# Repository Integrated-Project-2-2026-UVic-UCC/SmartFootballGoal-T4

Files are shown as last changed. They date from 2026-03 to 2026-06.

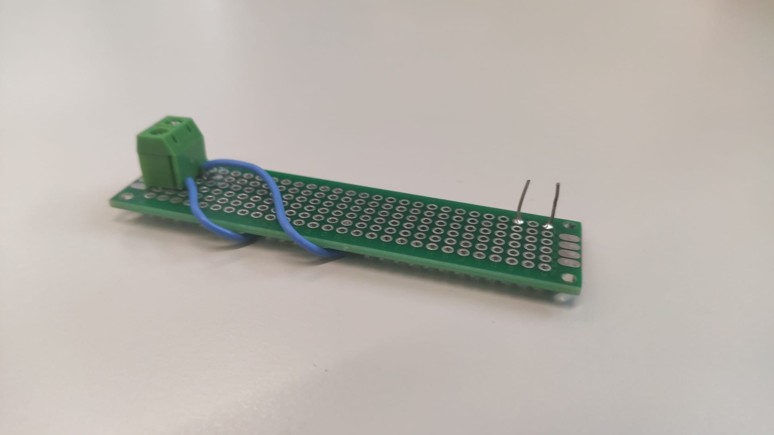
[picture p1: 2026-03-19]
Electronics/PCB 1.jpeg

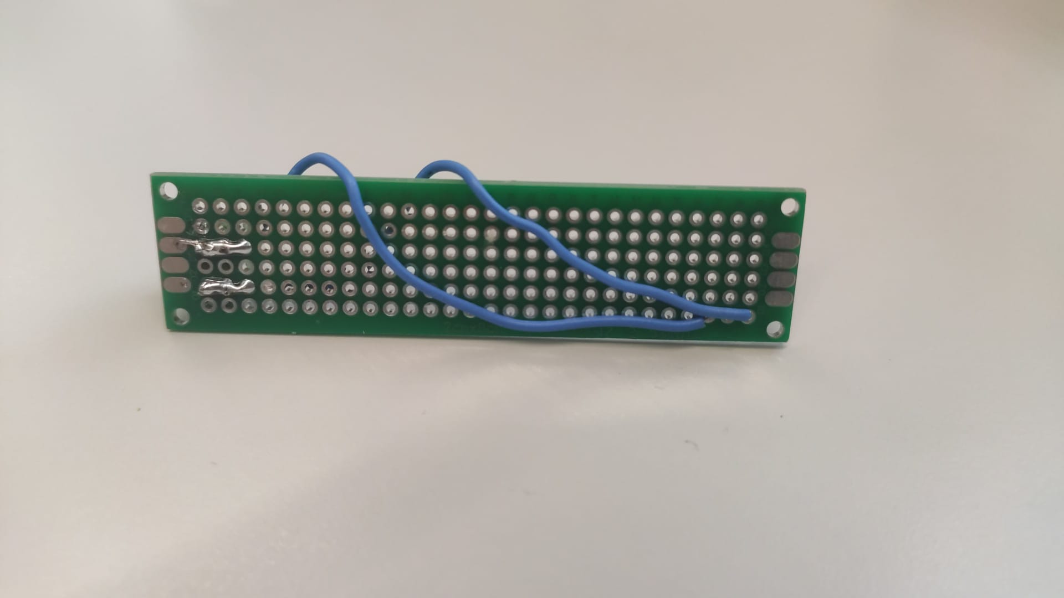
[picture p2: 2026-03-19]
Electronics/PCB 2.jpeg

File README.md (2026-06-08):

<div align="center">
  <h1>⚽ SmartGoal</h1>

  SmartGoal Demo (https://www.youtube.com/watch?v=oHqELqLCC2w)

</div>

### Computer-vision football goal with real-time ball tracking, speed measurement, and automatic slow-motion recording.

We are four Mechatronics Engineering students at UVIC and we built SmartGoal as our Integrated Projects II final prototype. The goal detects shots, measures ball speed in real time, records a slow-motion clip of every goal, and serves everything through a web dashboard hosted on the Raspberry Pi itself — no internet connection, no external infrastructure.

- Fully open-source — **hardware**, **software**, **firmware**.
- Runs on a **Raspberry Pi 4b** with a standard **Camera Module V2**.
- Ball tracking at up to **90 FPS** using OpenCV colour segmentation.
- **3D position and velocity** calculated from a single camera using the pinhole camera model.
- **4× slow-motion** goal clips saved automatically and accessible from any device on the local network.
- **Headless operation** — no monitor required after first setup.

---

## Built for tinkerers

SmartGoal is **not a finished product**. We built it in a university workshop with aluminium profiles, a drill press, and a 3D printer, and we expect you to do the same.

The aluminium goal frame is 100 cm wide, 65 cm tall, and 30 cm deep. The camera mounts on a custom support arm 60 cm behind and 35 cm above the crossbar. All structural parts are bolted together with M10 hardware — no welding required.

If you want a simpler build, you can mount the camera system on any existing goal of similar dimensions without building the frame from scratch.

---

## How it works

The camera captures frames at up to 90 FPS with a fixed 2000 µs exposure to keep the ball sharp at high speeds. Each frame is converted to HSV colour space and thresholded to isolate the ball. The largest matching contour is fitted with a minimum enclosing circle. If the circle radius exceeds the minimum threshold, the detection is accepted.

The detected radius in pixels is used to compute depth (Z axis) through the pinhole camera model: knowing the real ball diameter (20.4 cm) and the apparent pixel diameter, the system back-calculates the distance to the camera. Lateral position (X, Y) is derived from the pixel offset from the image centre scaled by the depth.

Velocity is the 3D Euclidean distance between consecutive positions divided by the elapsed time between frames, smoothed with an exponential moving average (α = 0.7).

A goal is registered when three conditions are met simultaneously: the ball is inside the configured depth window, speed exceeds the minimum threshold, and the cooldown period since the last trigger has elapsed.

When a goal is triggered, the system slices a 2-second window from the rolling frame buffer (1 s before and 1 s after the event), writes it at 1/4 of the real frame rate to produce 4× slow motion, re-encodes it to H.264 with ffmpeg for browser compatibility, and registers it with the web server.

---

# Getting started

## 1. Hardware

### 1.1 Electronics

| Component | Notes |
|---|---|
| Raspberry Pi 4b (4 GB or 8 GB) | Main processing unit |
| Raspberry Pi Camera Module V2 | Connected via CSI ribbon cable |
| USB-C power adapter (5 V / 3 A minimum) | Official Raspberry Pi adapter recommended |

Power the Raspberry Pi through the USB-C port. The camera draws power directly from the CSI connector — no additional wiring is needed.

### 1.2 Mechanical build

The goal frame uses 50 × 50 × 2 mm hollow square aluminium profiles bolted together with metallic angle brackets and M10 hardware.

**Dimensions:**
- Width: 1000 mm
- Height: 650 mm  
- Depth: 300 mm
- Rear support angle: 65.2° (calculated from the 650/300 geometry)
- Camera support arm: 600 mm horizontal + 350 mm vertical extension

**3D-printed parts** (PLA, designed in PTC Creo):
- End caps for open profile ends (45.90 × 43.40 mm, 2.50 mm height)
- Camera and Raspberry Pi enclosure support base (110 × 110 mm)
- Auxiliary fixation bracket (35 × 25 mm)

All STL files are in the `mechanical/` folder.

---

## 2. Software setup

### 2.1 Install dependencies

```bash
sudo apt update
sudo apt install -y python3-pip ffmpeg network-manager
pip3 install opencv-python picamera2 flask numpy
```

### 2.2 Clone the repository

```bash
git clone https://github.com/your-username/SmartGoal.git
cd SmartGoal
```

### 2.3 Configure the system

All parameters are in `config.py`:

```python
BALL_DIAMETER_M    = 0.204       # real ball diameter in metres
H_FOV              = 62.2        # horizontal field of view of your camera
IMG_W, IMG_H       = 640, 480    # capture resolution
CALIBRATION_FACTOR = 2.14        # lens distortion correction — recalibrate for your setup
HSV_LOWER          = (108, 134, 121)   # lower HSV bound for ball colour
HSV_UPPER          = (121, 255, 255)   # upper HSV bound for ball colour
GOAL_ZONE_NEAR     = 0.895       # near edge of goal plane in metres
GOAL_ZONE_FAR      = 0.905       # far edge of goal plane in metres
GOAL_MIN_VELOCITY  = 1.0         # minimum speed to register a goal (m/s)
SLOWMO_FACTOR      = 4           # slow-motion multiplier for saved clips
```

The HSV bounds and calibration factor depend on your ball colour and lens. See the calibration section below.

### 2.4 Run

```bash
python3 main.py
```

On startup the system creates a Wi-Fi hotspot named **SFGoal** (password: **football1**). Connect any device to that network and open `http://192.168.4.1:5000` in a browser to access the dashboard.

If an HDMI display is connected, a live preview window opens automatically. Without a display the system runs in headless mode — tracking, recording, and the web server all continue to work.

Press **Q** in the preview window or `Ctrl+C` in the terminal to stop.

---

## 3. Calibration

### 3.1 Ball colour (HSV thresholds)

Run the calibration tool with the system live:

```bash
python3 calibrate_hsv.py
```

Adjust the sliders until only the ball is visible in the mask preview. Copy the resulting `HSV_LOWER` and `HSV_UPPER` values into `config.py`.

### 3.2 Camera field of view

```bash
python3 calibrate_fov.py
```

Press `+` / `-` to adjust the crop factor until the goal opening fills the frame comfortably. Press `S` to save the resulting `H_FOV` value to `config.py`.

### 3.3 Depth calibration

Place the ball at a known distance from the camera (e.g. 1.00 m) and run the system. Read the reported Z value from the terminal or dashboard. Adjust `CALIBRATION_FACTOR` in `config.py` using:

```
CALIBRATION_FACTOR = CALIBRATION_FACTOR × (real_distance / reported_Z)
```

Repeat until the reported distance matches the real distance within acceptable error.

---

## 4. File structure

```
SmartGoal/
├── main.py          # entry point — initialises all components and runs the capture loop
├── config.py        # all tunable constants
├── detection.py     # detect_ball() — HSV segmentation and circle fitting
├── tracker.py       # BallTracker — 3D position and velocity from pixel detections
├── recording.py     # GoalRecorder — rolling buffer and background video writer
├── server.py        # Flask web dashboard
├── hotspot.py       # Wi-Fi hotspot management
├── sources.py       # CameraSource — PiCamera2 wrapper
├── drawing.py       # draw_ball() — live preview annotation
├── calibrate_fov.py # interactive FOV calibration tool
└── mechanical/      # STL files and CAD drawings
```

---

## 5. Troubleshooting

**Camera not found / PiCamera2 error**

Make sure no other process is using the camera:

```bash
sudo pkill -f python3
sudo fuser -k /dev/video0 2>/dev/null
sleep 2
python3 main.py
```

**Hotspot not starting**

```bash
sudo apt install -y network-manager
sudo systemctl enable NetworkManager
sudo systemctl start NetworkManager
```

**Videos not playing in the browser**

ffmpeg must be installed for H.264 re-encoding:

```bash
sudo apt install -y ffmpeg
```

**Ball not detected**

Recalibrate the HSV thresholds under your current lighting conditions. Detection is sensitive to ambient light changes — the system works best under consistent indoor lighting.

---

## Built by

Sergi Ocaña, Mireia Sabaté, Martí Sayago, Oleguer Treserra  
Degree in Mechatronics Engineering — UVIC, 2026

Tutor: Clara I. Sandino, Moises Garin Escriva
```

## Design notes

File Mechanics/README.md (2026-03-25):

## 🏗️ Mechanical Design: Field Deployment

The mechanical structure ensures the electronics survive the impact and environmental conditions of a football pitch.

### 📐 Optimal Geometry
- **FOV Coverage:** Based on the lens's **62.2° HFOV**, the camera is mounted exactly **75 cm** from the goal line. This allows the system to monitor the entire **90 cm x 60 cm** goal aperture in a single frame.
- **Angle of Attack:** The camera is positioned at a slight incline to maximize the visible "Z-depth" as the ball approaches the net.

### 🛡️ Impact & Protection
- **Vibration Isolation:** The Raspberry Pi is mounted on rubber standoffs inside the case to protect the CPU and SD card from the shock of the ball hitting the frame.
- **Lens Shield:** A high-transparency polycarbonate plate protects the camera lens from high-velocity direct impacts without distorting the optical path.

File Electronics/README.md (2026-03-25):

## ⚡ Electronics: High-Performance Edge Computing

The electronic heart of SmartGoal is designed for low-latency image processing and stable high-speed data acquisition.

### 🧠 Core Components
- **Raspberry Pi 4 (8GB RAM):** Handles the parallel execution of the OS, camera stream, and OpenCV mathematical calculations.
- **Sony IMX219 Camera Module:** An 8MP sensor capable of high-speed video modes (90-120 FPS), connected via a dedicated 15-pin **CSI (Camera Serial Interface)**.
- **Power Management:** 5V/3A USB-C power delivery with an integrated 10,000mAh battery for 4+ hours of pitch-side operation.
- **Thermal Solution:** Active cooling (PWM Fan) and aluminum heatsinks to prevent CPU throttling during intensive 3D math processing.

### 🔌 Connectivity & Signal Flow
1. **Raw Input:** The IMX219 sensor sends raw Bayer data through the CSI bus to the Pi's GPU.
2. **Hardware Decoding:** The ISP (Image Signal Processor) converts data to a BGR888 array.
3. **Feedback Output:** Real-time data is displayed via Micro-HDMI or transmitted over 5GHz Wi-Fi for remote monitoring.

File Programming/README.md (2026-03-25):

## 💻 Programming: The Vision Pipeline

The software architecture is a custom-built **Object Tracking & Physics Engine** written in Python 3.

### 👁️ Computer Vision Pipeline
- **HSV Space Isolation:** To handle changing outdoor light, the code converts frames to **HSV (Hue, Saturation, Value)**. This allows for stable color tracking even under heavy shadows or bright sunlight.
- **Morphological Filtering:** Uses **Gaussian Blurring**, **Erosion**, and **Dilation** to eliminate "salt and pepper" noise from the grass and player movement.
- **Circularity Algorithm:** To prevent tracking non-ball objects, every detected shape is put through a circularity test:
  $$Circularity = 4\pi \times \frac{Area}{Perimeter^2}$$
  *Only objects with a ratio $> 0.6$ (indicating a spherical shape) are accepted.*

### 📐 3D Physics Engine
- **Depth Estimation (Z-axis):** Based on the **Pinhole Camera Model**, the code calculates ball distance by comparing its pixel diameter to its real-world size (22.5cm):
  $$Z = \frac{BallDiameter \times FocalLength}{PixelDiameter}$$
- **3D Velocity Vector:** The system tracks the Euclidean distance between frames in a 3D coordinate system $(X, Y, Z)$:
  $$\text{Speed} = \frac{\sqrt{\Delta X^2 + \Delta Y^2 + \Delta Z^2}}{\Delta Time}$$
- **Smoothing:** A weighted **Exponential Moving Average (EMA)** filter stabilizes the speed output, removing jitter from pixel noise.

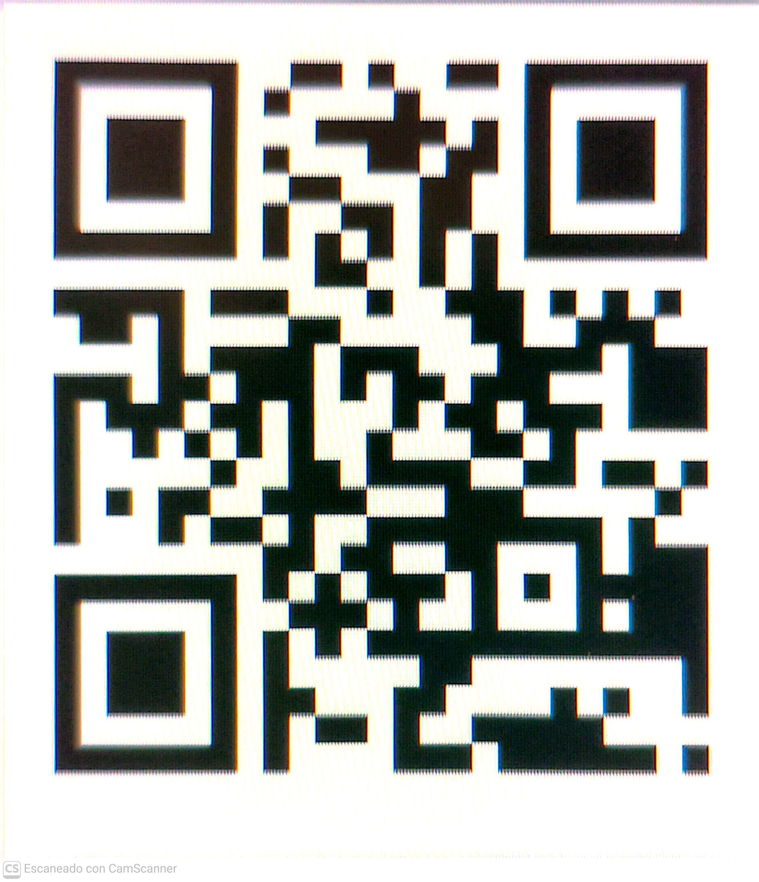
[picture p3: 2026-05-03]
Programming/football_goal/Final_version/QR_wifi.jpg

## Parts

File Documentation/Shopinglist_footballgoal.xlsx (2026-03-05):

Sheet: Project Specifications
TECHNICAL SPECIFICATIONS
Customer Company | Universitat de Vic - Universitat Central de Catalunya
Engineering Company | Smart Football Goal
Revision 1 | Date: 5/03/2026
List the main characteristics of the desired device
Item number | Description
1 | Capable of registering the velocity and position of the ball
2 | Dureble enought to handle shoots in any direction
3 | Collects the information and sends it to a webpage
Mechanical part
Dimensions (volume) | 600 mm x 300 mm x 900 mm (height)
Weight | 5,8 kg (aprox)
Wheels | no weels
Materials for the mechanical part / structure | 3D printed parts and aluminium tube
Motors | no motor
Degrees of freedom | 0
Manufacturing equipment | 3D Printer, industrial drills, cutting machines
Assembly between parts | Bolts and nuts, welding for electrical and electronics parts
Electronic & programming part
Microcontroller | Raspberry Pi 5 4GB
Drivers | Native driver (so no needed)
Sensors | Arducam IMX296 Global Shutter Camera
Communication | Via Wifi
Programming | Phython and OpenCv
Power | Connected to the socket
Autonomy | Indef
Protoboard | No

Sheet: Conceptual_Design
CONCEPTUAL DESIGN
Include an image (or more than one) with the current status of the conceptual design. Can be a sketches done with pencil

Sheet: Shopping list
PRELIMINAR ORDER LIST
Team: | smart football goal(team 4) |  |  | Total cost [€] | 271.17 |  | 28.83
 |  |  |  | Budget limit [€] | 300
Item number | Description of the material | Quantity |  | Price [€] | Cost [€] | Provider | Link / website
1 | goalpost tubes | 6 | m | 6.56 | 39.36 |  | https://www.alacermas.com/es/producto/tubos-cuadrados-extruidos-de-aluminio | .
2 | ESP 32 | 1 |  | 8.90 | 8.90 |  | https://www.amazon.es/desarrollo-AYWHP-ESP-WROOM-32-Bluetooth-Compatible/dp/B0DG8JFY3C | .
3 | regulator (5 a 3,3v) | 1 |  | 11.99 | 11.99 |  | https://www.amazon.es/Convertidor-ajustable-reductor-regulador-voltaje/dp/B0D9HSRQSB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
4 | Cargols M8 85mm | 20 | en el paquet hi ha 30, pero nomes necessitarem aprox 20 | 15.87 | 15.87 |  | https://www.tornillos-express.es/carrito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 | ,
6 | femella M8 85mm | 20 | en el paquet hi ha 100, pero nomes necessitarem aprox 20 | 1.33 | 1.33 |  | https://www.tornillos-express.es/tornillo-metales-cabeza-hexagonal-th-109-iso-4017/43047-632626-tornillo-metales-cabeza-hexagonal-m8x80-clase-109-acero-cincad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
7 | Goal net | 1 |  | 25.66 | 25.66 |  | https://www.amazon.es/dp/B0CJJCG4B2?aref=WCCGjsiMEK&sp_csd=d2lkZ2V0TmFtZT1zcF9kZXRhaWw | ,
8 | Arducam IMX296 Global Shutter Camera | 1 |  | 70.99 | 70.99 |  | https://www.arducam.com/1-58mp-imx296-color-global-shutter-camera-module-with-m12-lens-for-raspberry-pi.html | . | price arducam
9 | Raspberry Pi 5 4GB | 1 |  | 97.07 | 97.07 |  | https://www.amazon.es/Raspberry-Pi-SC1111-5-4Gb/dp/B0CK3L9WD3?__mk_es_ES=ÅMÅŽÕÑ | .
10 |  |  |  |  | 0
11 |  |  |  |  | 0
12 |  |  |  |  | 0
13 |  |  |  |  | 0
14 |  |  |  |  | 0
15 |  |  |  |  | 0
16 |  |  |  |  | 0
17 |  |  |  |  | 0
18 |  |  |  |  | 0
19 |  |  |  |  | 0
20 |  |  |  |  | 0

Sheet: Recommended suppliers
Provider | Description | link
RS Online | distributor of electronics, electricity and industrial maintenance products | https://es.rs-online.com/
BCN 3D Technologies | 3D Printing Filament distributor for our 3D printer BCN 3D Sigma | https://www.bcn3dtechnologies.com/ca/
Robotshop | Stepper motor, grippers, servo motors, arduinos, raspberry Pi, drivers for motors | https://www.robotshop.com/
Motedis | Mechanical components, aluminium profiles | https://www.motedis.es/shop/index.php
Amazon | Electronics and more | https://www.amazon.es/
ALACER MAS | Mechanical components, aluminium profiles | http://www.alacermas.com/index.php
Please check also the list of recommended providers in the virtual campus.
https://campus.uvic.cat/aules/pluginfile.php/830007/mod_resource/content/2/IP2_List_of_possible_providers.pdf

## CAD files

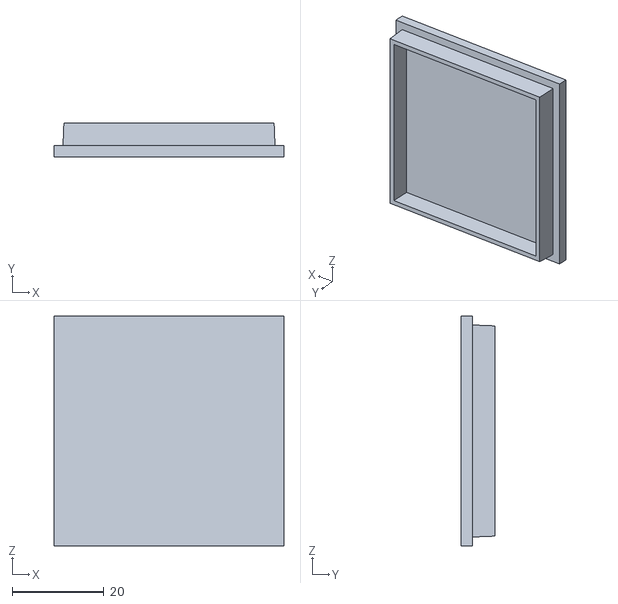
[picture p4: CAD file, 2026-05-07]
Mechanics/tapaporteria.stl
50.0 x 7.50 x 50.0

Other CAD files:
Mechanics/Soporte_RASPI_LLARG.dwg
Mechanics/tapaporteria2.0..stl

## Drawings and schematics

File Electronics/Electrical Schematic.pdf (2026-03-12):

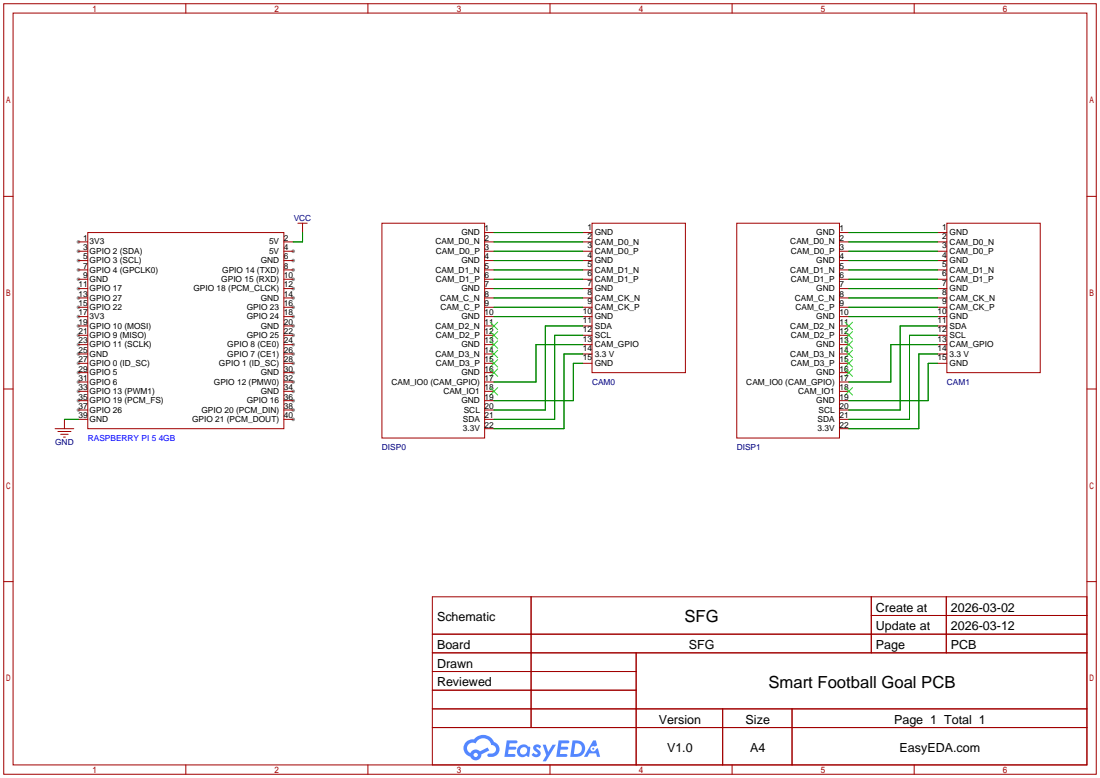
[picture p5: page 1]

GPIO 18 (PCM_CLCK) 12 GPIO 15 (RXD) 10 GPIO 14 (TXD) 8

Schematic | SFG | Create at | 2026-03-02

Update at | 2026-03-12

Board | SFG | Page | PCB
Drawn | | Smart Football Goal PCB
Reviewed

Version | Size | Page 1 Total 1
V1.0 | A4 | EasyEDA.com

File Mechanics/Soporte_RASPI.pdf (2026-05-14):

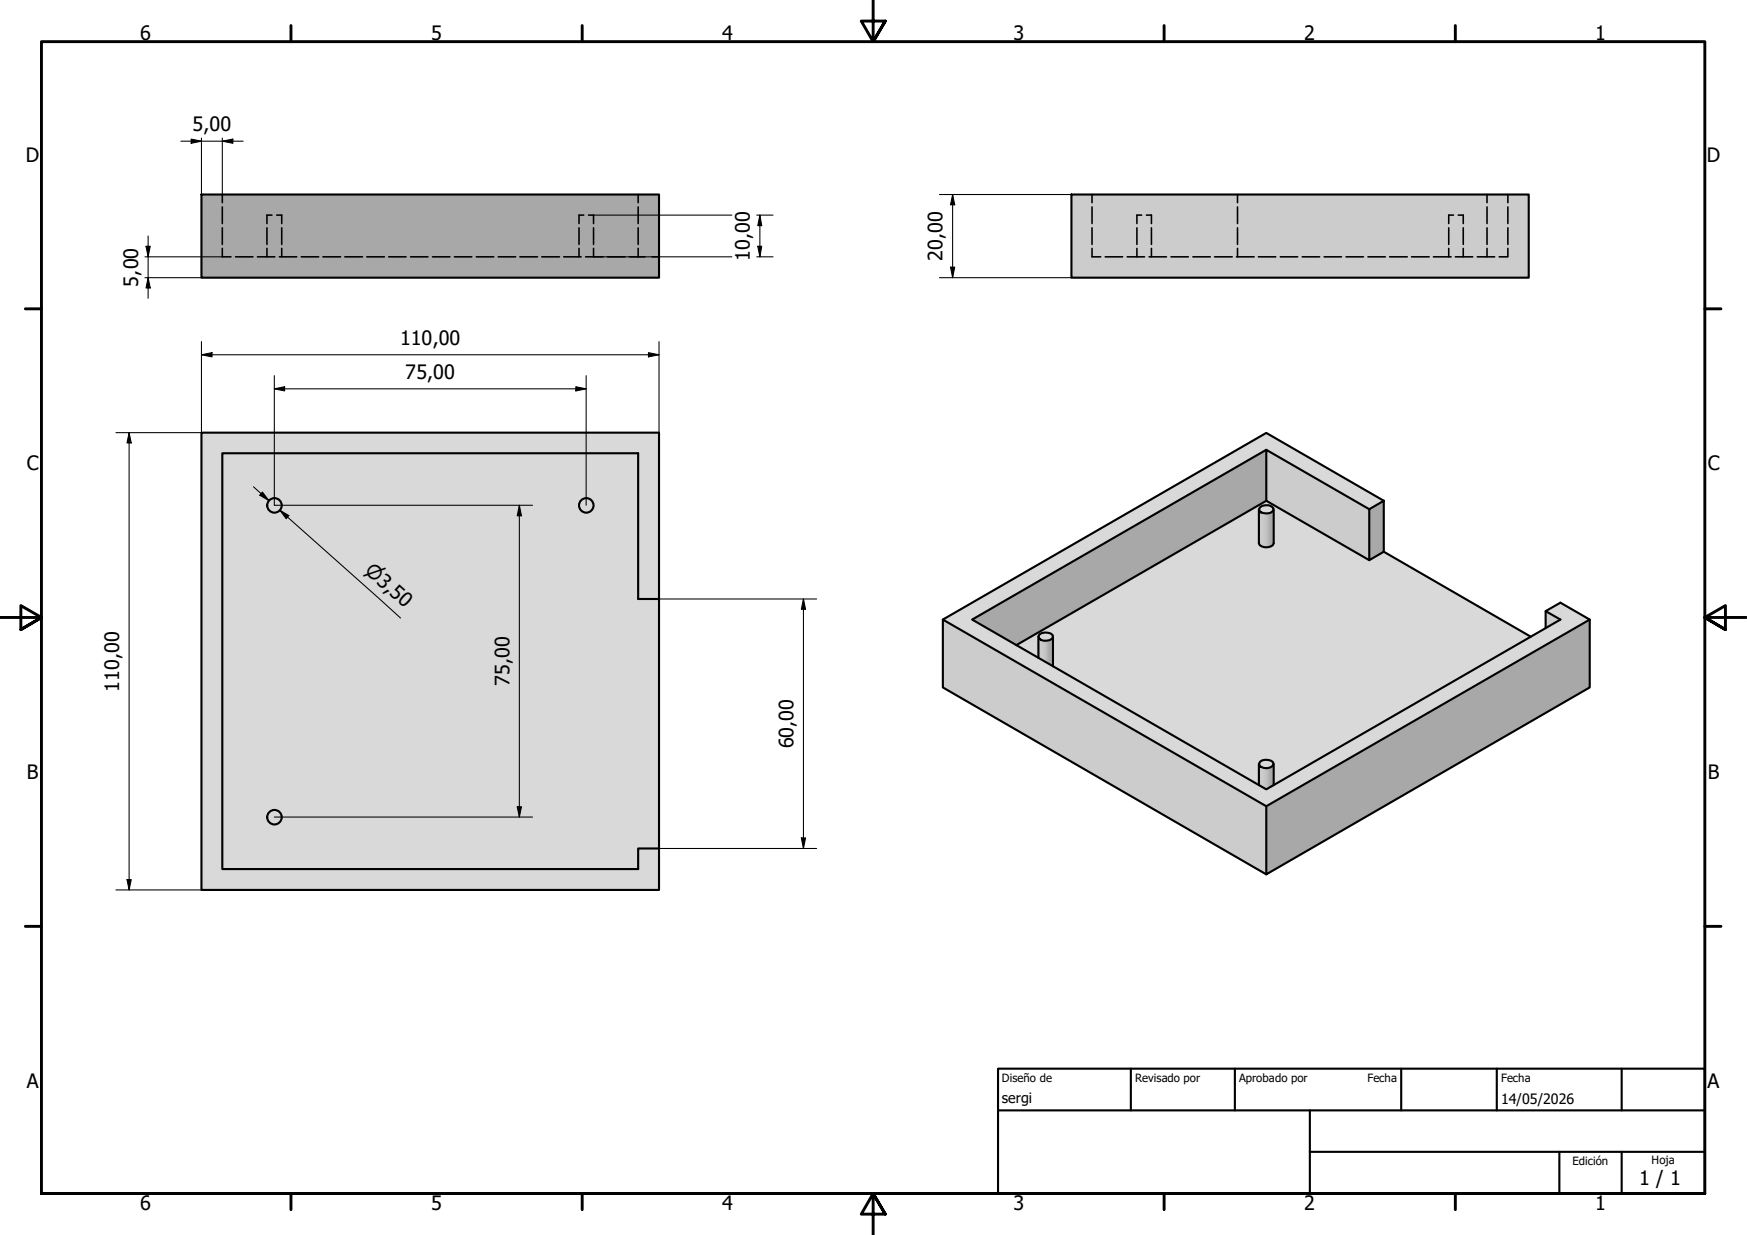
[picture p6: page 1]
Diseño de; Revisado por; Aprobado por; Fecha

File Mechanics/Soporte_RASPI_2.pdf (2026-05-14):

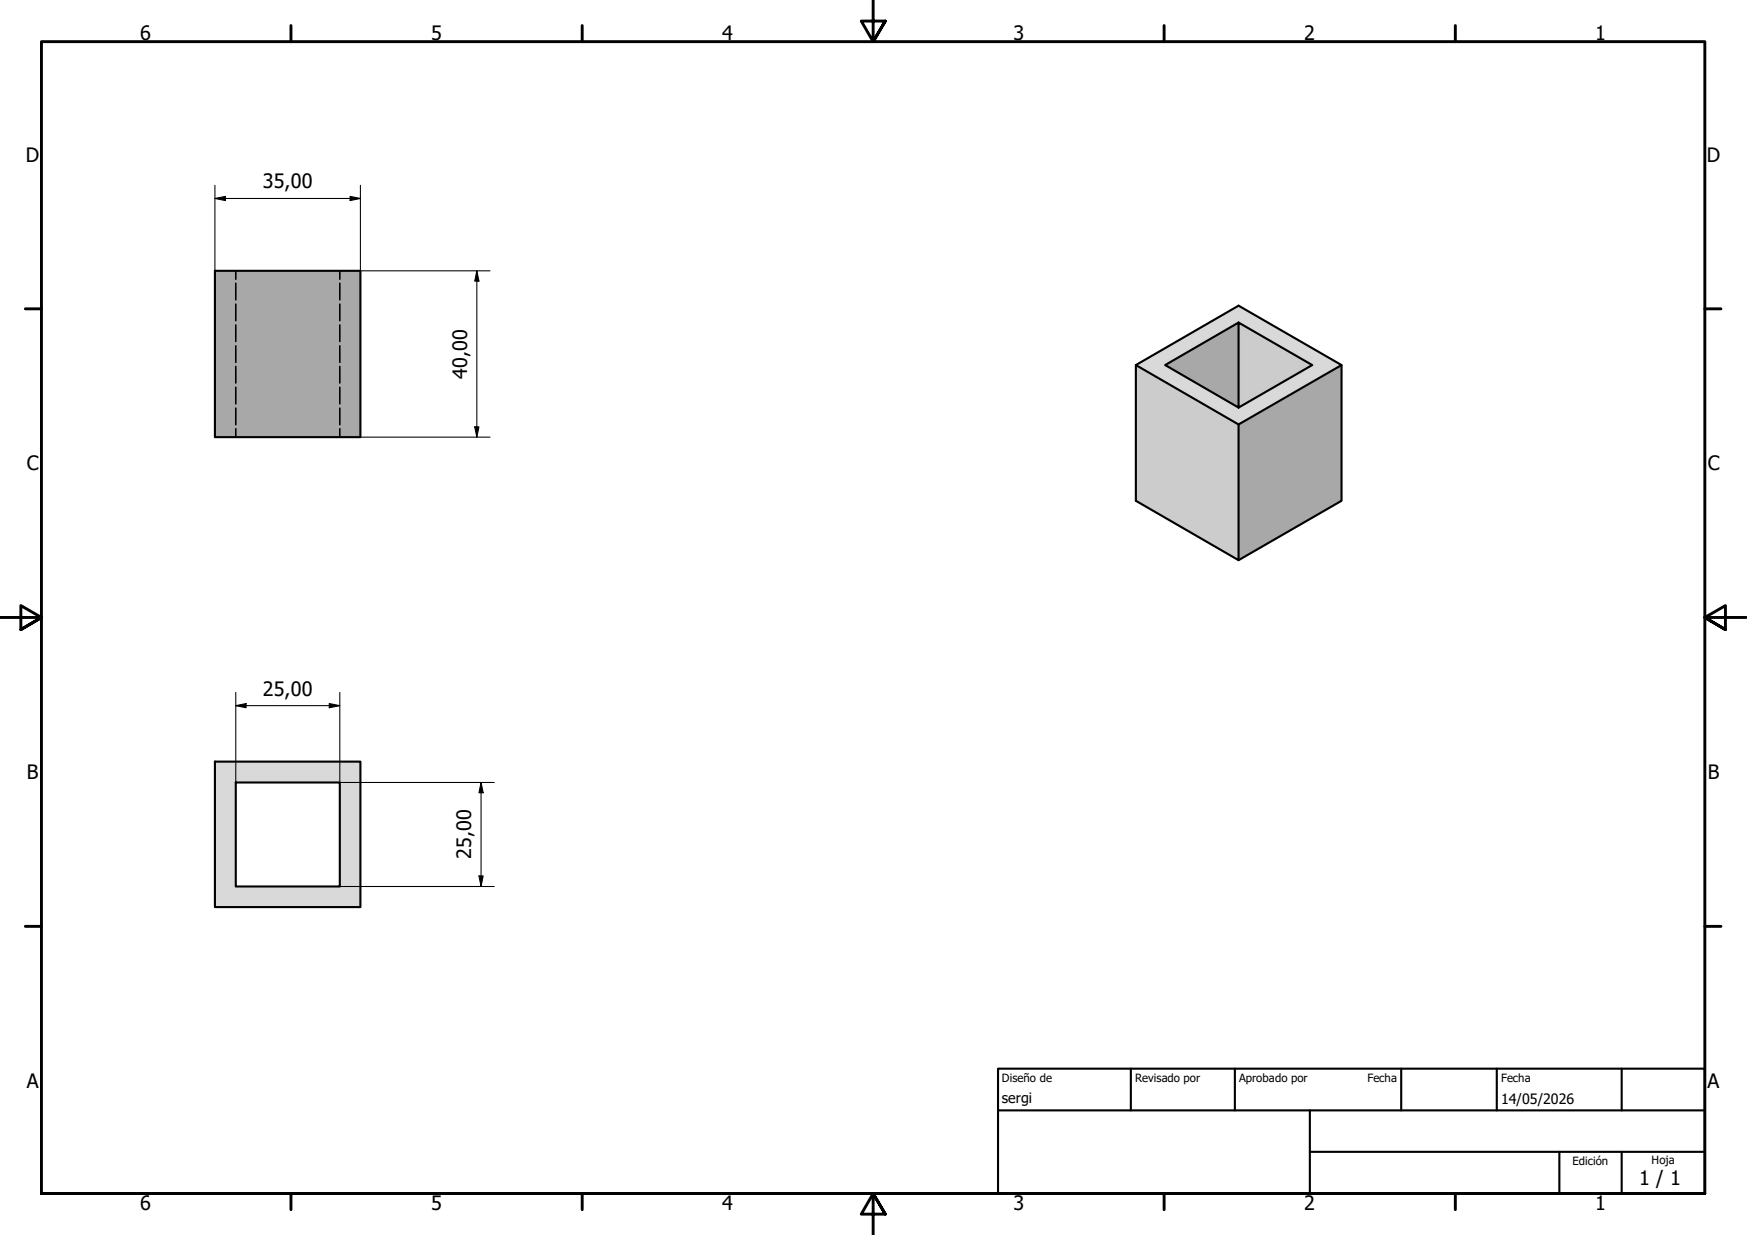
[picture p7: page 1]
Diseño de; Revisado por; Aprobado por; Fecha

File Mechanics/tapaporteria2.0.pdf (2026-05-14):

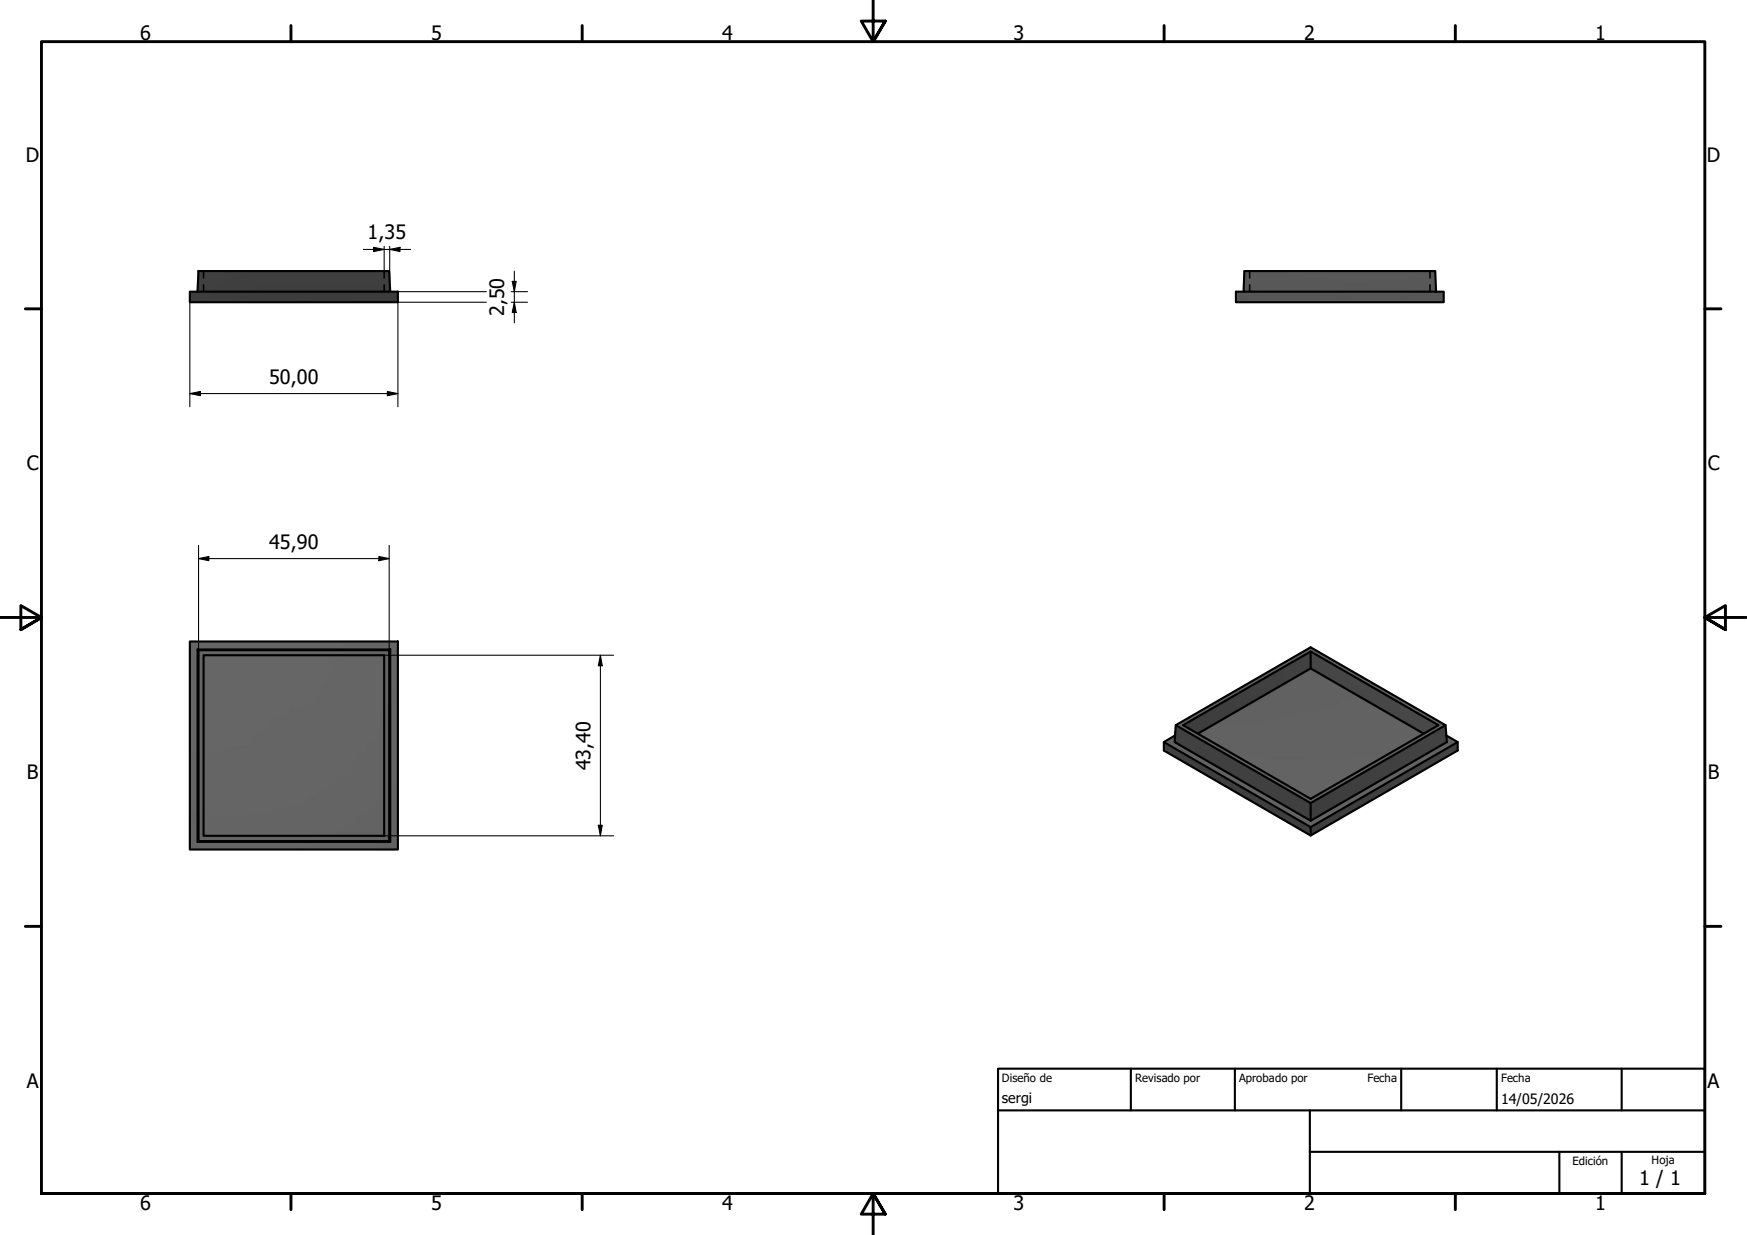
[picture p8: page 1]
Diseño de; Revisado por; Aprobado por; Fecha

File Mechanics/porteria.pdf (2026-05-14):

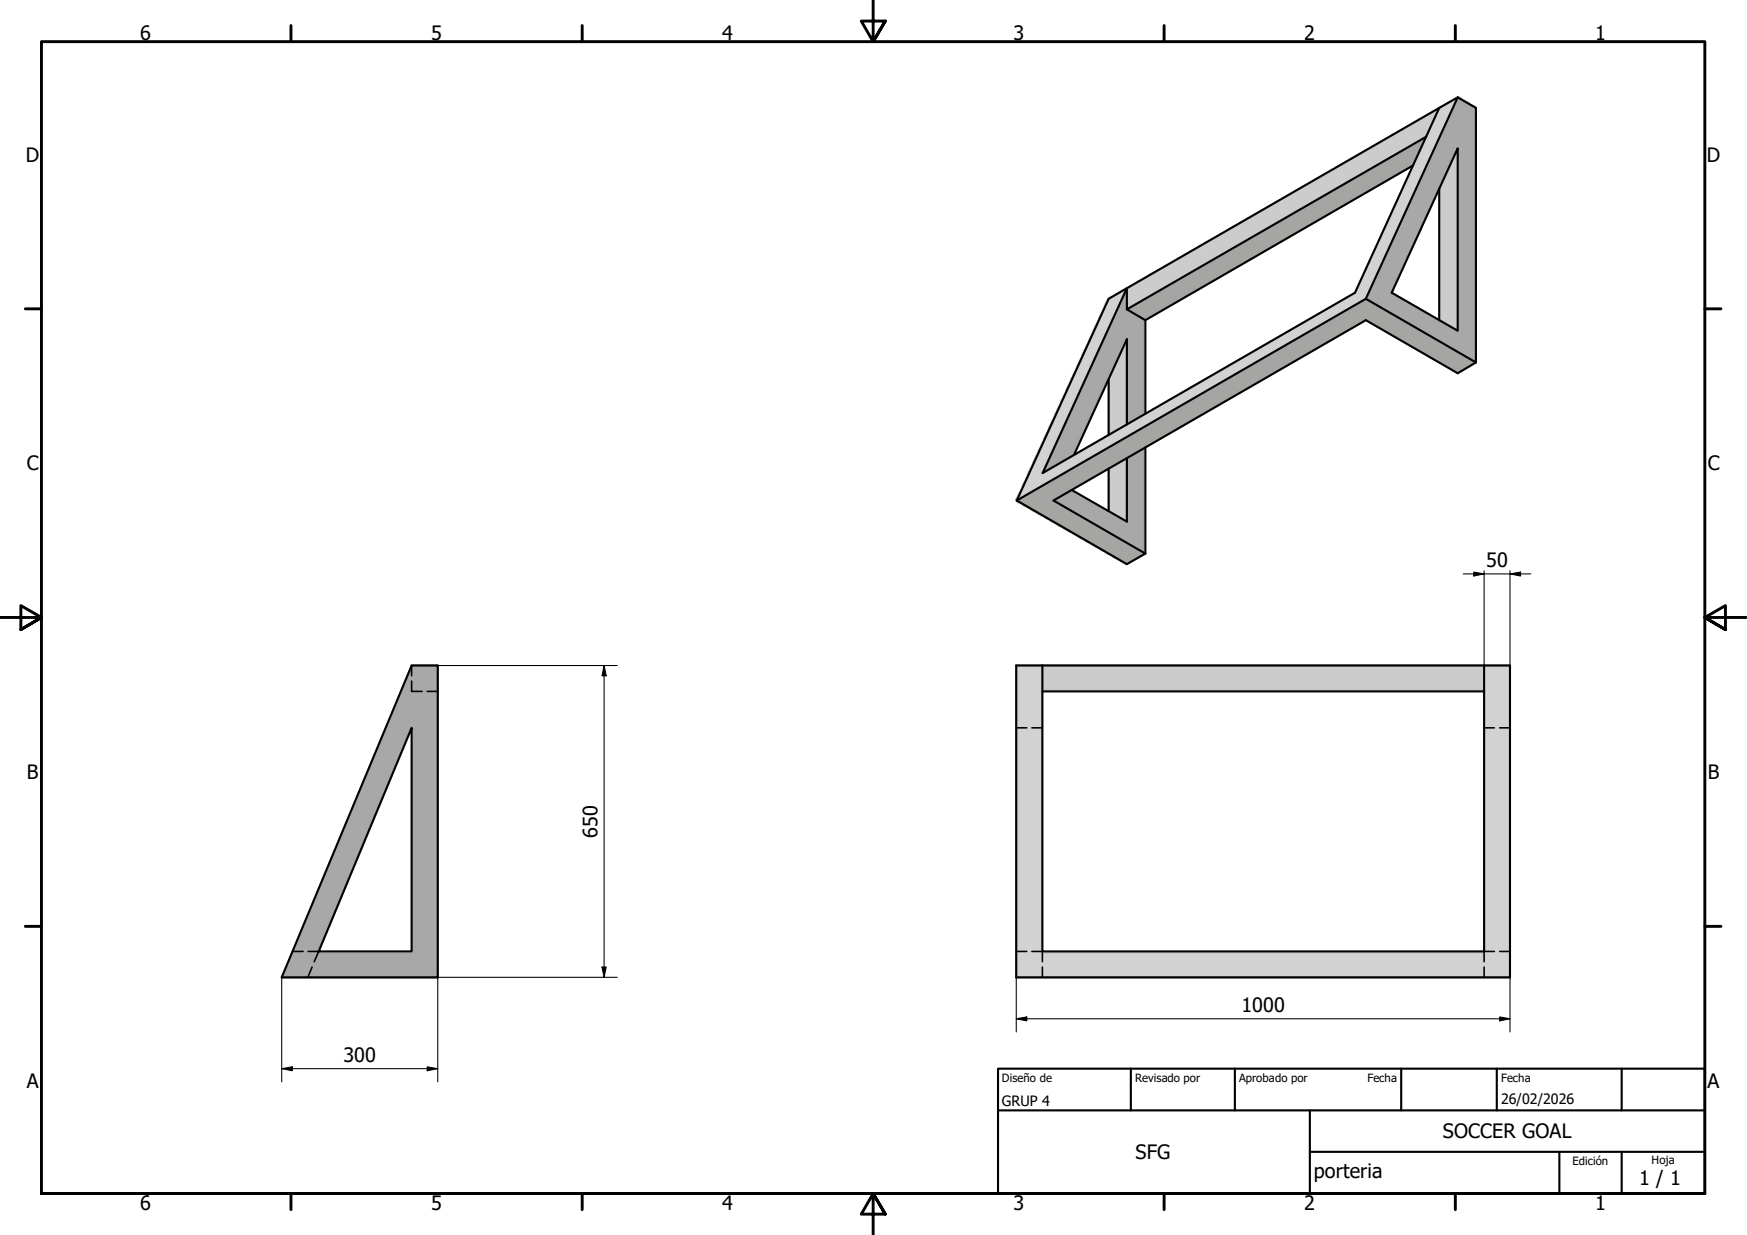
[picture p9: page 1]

Diseño de GRUP 4 | Revisado por | Aprobado por Fecha | Fecha 26/02/2026

SFG | SOCCER GOAL

porteria | Edición | Hoja 1 / 1

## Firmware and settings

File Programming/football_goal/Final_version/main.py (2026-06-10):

"""
main.py
───────
Entry point.  Run with:  python main.py

Works with or without a display (headless):
  - With HDMI: shows a real-time OpenCV (cv2) window.
  - Without HDMI: skips the entire UI; tracking and recording work exactly the same.

Goal clip recording is triggered when ALL three conditions are true:
  1. Ball is inside the goal zone      (GOAL_ZONE_NEAR ≤ z ≤ GOAL_ZONE_FAR)
  2. Ball velocity exceeds minimum     (velocity > GOAL_MIN_VELOCITY)
  3. Cooldown has elapsed              (≥ GOAL_SEND_INTERVAL s since last trigger)

Press Q to quit (display mode only).
"""

import atexit
import os
import time
import cv2

import config
import server
import hotspot
import recording
from sources   import build_source
from detection import detect_ball
from tracker   import BallTracker
from drawing   import draw_ball


def _has_display() -> bool:
  """Returns True if a display server is available."""
  # On a headless Linux system (e.g., a Raspberry Pi without HDMI),
  # DISPLAY and WAYLAND_DISPLAY will be unset. We check both before
  # attempting to use OpenCV.
    if os.environ.get("DISPLAY") or os.environ.get("WAYLAND_DISPLAY"):
       # Secondary check: verify that OpenCV can actually create a window.
        try:
            cv2.namedWindow("__test__", cv2.WINDOW_NORMAL)
            cv2.destroyWindow("__test__")
            return True
        except Exception:
            return False
    return False


def run_loop(source, tracker: BallTracker, recorder: recording.GoalRecorder,
             headless: bool) -> None:
    last_trigger_time = 0.0

    if headless:
        print("[INFO] Headless mode — no screen to see the process.")

    try:
        while True:
            ok, frame = source.read()
            if not ok:
                break

            current_time = time.time()
            detection    = detect_ball(
                frame, config.HSV_LOWER, config.HSV_UPPER, config.MIN_RADIUS
            )

            if detection:
                x_px, y_px, radius = detection
                result = tracker.update(x_px, y_px, radius, current_time)

                # ── Goal detection and recording trigger ────────────────────
                in_zone     = config.GOAL_ZONE_NEAR <= result["z_m"] <= config.GOAL_ZONE_FAR
                fast_enough = result["velocity"] > config.GOAL_MIN_VELOCITY
                cooldown_ok = (current_time - last_trigger_time) >= config.GOAL_SEND_INTERVAL

                if in_zone and fast_enough and cooldown_ok:
                    server.record_velocity(result["velocity"], result["z_m"])
                    recorder.trigger_goal(current_time, result["velocity"], result["z_m"])
                    last_trigger_time = current_time
                # ─────────────────────────────────────────────────────────

                if not headless:
                    draw_ball(frame, x_px, y_px, radius, result["z_m"], result["velocity"])

            else:
                tracker.reset()

            # Feed the annotated frame into the rolling buffer every frame
            # In headless the frame dosn't have anotations 
            #---------------------------------------
            recorder.add_frame(frame, current_time)

            if not headless:
                cv2.imshow("Ball Velocity Tracker", frame)
                if cv2.waitKey(1) & 0xFF == ord('q'):
                    break
            else:
                # Without a display: yield CPU time to the OS so the recording and server
                # threads can continue running.
                # 10 ms is sufficient at 90 FPS (the main loop takes ~11 ms per frame).
                time.sleep(0.010)

    finally:
        source.release()
        if not headless:
            cv2.destroyAllWindows()


def main():
    print("[INFO] Starting ball tracker.")

    # ── 1. Bring up the WiFi hotspot ─────────────────────────────────────────
    info = hotspot.start()
    atexit.register(hotspot.stop)

    # ── 2. Tell the web server about the hotspot ──────────────────────────────
    server.set_hotspot_info(
        ssid     = info["ssid"],
        password = info["password"],
        url      = info["url"],
    )

    # ── 3. Start the Flask server ─────────────────────────────────────────────
    server.start()

    # ── 4. Detect display availability ───────────────────────────────────────
    headless = not _has_display()

    # ── 5. Start tracker and recorder ────────────────────────────────────────
    source   = build_source(config)
    tracker  = BallTracker(config)
    recorder = recording.GoalRecorder(server, config)

    run_loop(source, tracker, recorder, headless)

    print("[INFO] Tracker stopped.")


if __name__ == "__main__":
    main()

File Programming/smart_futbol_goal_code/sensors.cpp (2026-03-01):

#include "sensors.h"
#include "score.h"
#include <Wire.h>
#include <VL53L1X.h>
VL53L1X sensor[NUM_SENSORS];
int sensorScoreMult[NUM_SENSORS] = { 5, 3, 1, 3, 5 };

int distance1 = 0;
int distance2 = 0;
int sensorIndex1 = -1;
int sensorIndex2 = -1;

bool firstDetected = false;
bool waitingSecond = false;
int detectedCount = 0;

unsigned long firstDetectTime = 0;

void startSensors() {
  Wire.begin();
  for (int i = 0; i < NUM_SENSORS; i++) {
    sensor[i].init();
    sensor[i].setDistanceMode(VL53L1X::Short);  //change this in different distances, for the moment short
    sensor[i].setMeasurementTimingBudget(50000);
    sensor[i].startContinuous(50);
    sensor[i].setROISize(4, 4);  //Measurament region of interest, the lowest posible = 4, highest = 16
  }
}

float readSensors() {

  for (int i = 0; i < NUM_SENSORS; i++) {

    int distance = sensor[i].readRangeContinuousMillimeters();

    if (abs(distance - STANDARD_DISTANCE) > TOLERANCE) {

      if (!firstDetected) {
        distance1 = distance;
        sensorIndex1 = i;
        firstDetected = true;
        waitingSecond = true;
        firstDetectTime = millis();
        Serial.print("Distance 1: ");
        Serial.println(distance1);
      }

      else if (waitingSecond && detectedCount < 2) {

        if (millis() - firstDetectTime >= WAIT_TIME) {
          distance2 = distance;
          sensorIndex2 = i;
          waitingSecond = false;
          detectedCount = 2;
          Serial.print("Distance 2: ");
          Serial.println(distance2);
        }
      }
    }
  }

  // If there is a goal, calculate score
  if (firstDetected) {
    float score = calculateScore();
    detectedCount = 0;
    firstDetected = false;

    Serial.print("Score: ");
    Serial.println(score);

    return score;  // send score to main
  } else {
    return 0;
  }
}

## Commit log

2026-03-19 Raspberri Pi case with Pi Camera
2026-03-25 Revise README for Electronics: Update components and flow
    Updated the README to reflect changes in the electronics architecture and system overview for SmartGoal.
2026-03-25 Fix formatting and update modular mounting description
2026-03-26 Refactor camera settings and ball tracking logic
    Updated ball diameter, trajectory buffer, and color detection settings. Changed camera configuration to output BGR format and adjusted speed calculation logic.
2026-04-09 Refactor ball detection and distance calculations
    Updated ball diameter and calibration factor. Improved ball detection and distance calculation methods.
2026-04-14 Refactor ball tracking and velocity calculations
2026-04-28 Actualized using threads
2026-06-05 Fixed minor bugs
    Fixed minor bugs and improved performance and fov issues
    [calibrate_fov.py, main.py, recording.py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]
2026-06-10 Translate comments and instructions to English
    Updated comments and printed instructions to English for consistency.
